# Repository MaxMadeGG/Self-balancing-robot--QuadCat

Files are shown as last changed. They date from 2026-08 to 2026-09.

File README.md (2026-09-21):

# Self-balancing robot- QuadCat

Wheel-legged balancing robot. Two gimbal motors drive the wheels with my own FOC code, two servos move the legs so it can crouch, and an MPU-6050 is used for balancing.
> **Status:** Work in progress. This repository currently contains the v2.0 custom PCB design, schematic and ownFOC code.
[DEMO](https://youtube.com/shorts/aNbwgdx8i7I?si=RKKSs-6FwYw2KxhV)
## Parts

| Part | Notes |
|---|---|
| ESP32 NodeMCU-32S | 30 pin |
| 2x SimpleFOC Mini (DRV8313) | needs at least 8 V |
| 2x gimbal motor | 7 pole pairs, ~35 Ω |
| 2x AS5600 | encoders, address 0x36 (can't be changed) |
| MPU-6050 | 0x68 |
| 2x MG90S | leg servos |
| 2x VL53L0X | distance sensors, not tested yet on the v2.0 |
| 2S LiPo 2600 mAh | |
| XL6009 boost | 10 V for the drivers |
| Buck converter | 5 V for the ESP32 and servos |
| 2x 220 µF cap | one on each driver, needed or the ESP32 resets |

## Schematic and PCB


The full schematic and PCB files are in the repo. The encoders both use address 0x36, so each one is on its own I2C bus.
It was made in easyEDA.
[gerber](self-balancing-robot-cat-gerber-v2.0.zip)
[schematic](schematic.epro2)
[PCB](PCB.epro2)

## Things to know

- GPIO 5, 12 and 27 need a 10k pulldown to GND. 5 and 12 are strapping pins, and if 12 is high at boot the ESP32 won't boot. Without the pulldown on the EN pins the drivers can turn on by themselves.
- AS5600: the chip has to face the magnet, about 1 mm away and flat. Check the AGC register, around 120-180 is good, 255 means too far.
- Reading the MPU at 2 kHz on the same bus as an encoder didn't work. 200 Hz is fine.
- Trim the header pins! Two pins touched on a driver (EN and nFAULT), the driver stayed on all the time and it killed an ESP32.

## Problems I had

Board v1:
- only one GND pin was really connected, it worked on USB but not on battery
- broken trace to SV2
- the two I2C buses were merged, so both encoders answered on 0x36 (couldn't fix)
- no caps on the drivers, the ESP32 reset during calibration
- encoder cables crossed and encoder direction inverted (fixed in code)
> **Note:** These v1 issues have all been resolved in the v2 layout included in this repository.

Board v2:
[gerber](self-balancing-robot-cat-gerber-v2.0.zip)
[schematic](schematic.epro2)
[PCB](PCB.epro2)
- motor 1 IN3 and EN were swapped in my code, so motor 1 only twitched. Took a while to find...
- SV2 is on GPIO12, not 13
- encoders were mounted the wrong way and too far from the magnet

## Software

I don't use the SimpleFOC library. On my board it didn't output any PWM, so I wrote my own [FOC](Quad-code-ownFOC.zip) using ledcWrite. The servos also use ledcWrite directly instead of ESP32Servo, so they don't fight with the motors over timers.

The control loop runs at a fixed 2 kHz. More about the code later.

## To do

- [ ] pulldowns on 5, 12 and 27
- [ ] test the lasers and battery reading
- [ ] finish the body
- [ ] balance loop
- [ ] ESP-NOW remote - connect to Kode dot and the Pinetime watch to control the robot by yourself
- [ ] make the robot autonomous

## Mechanical

Coming later...
You can still make your own robot with this working PCB, you will just need to tune the code (me i can't due to the ESP32 that broke)

## License

See [LICENSE](LICENSE.md).

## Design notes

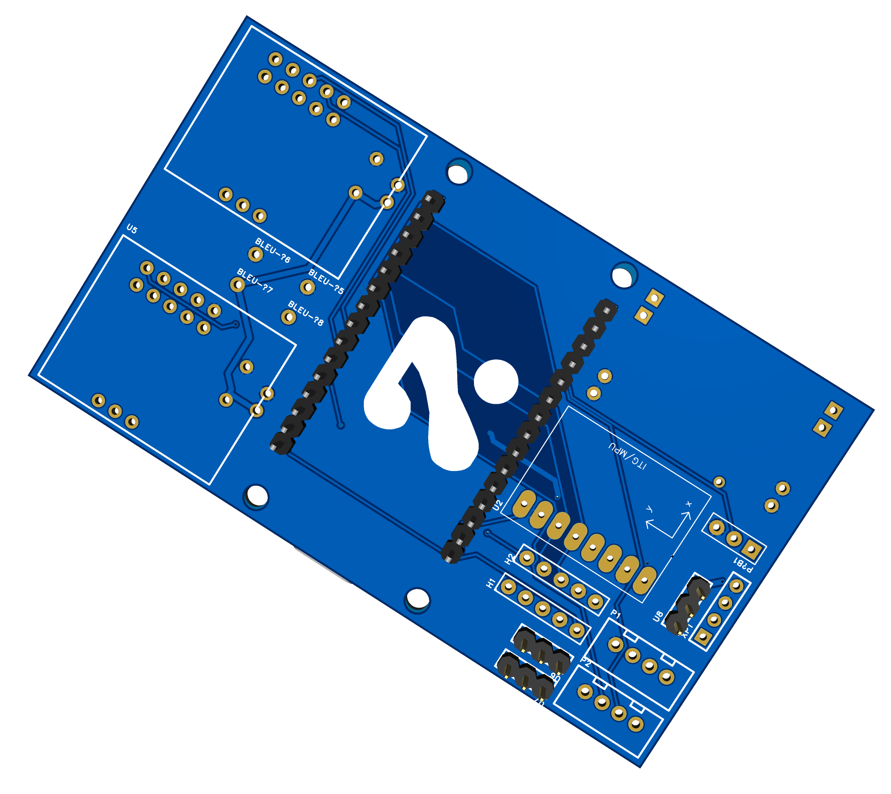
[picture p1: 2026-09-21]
3D_PCB.png

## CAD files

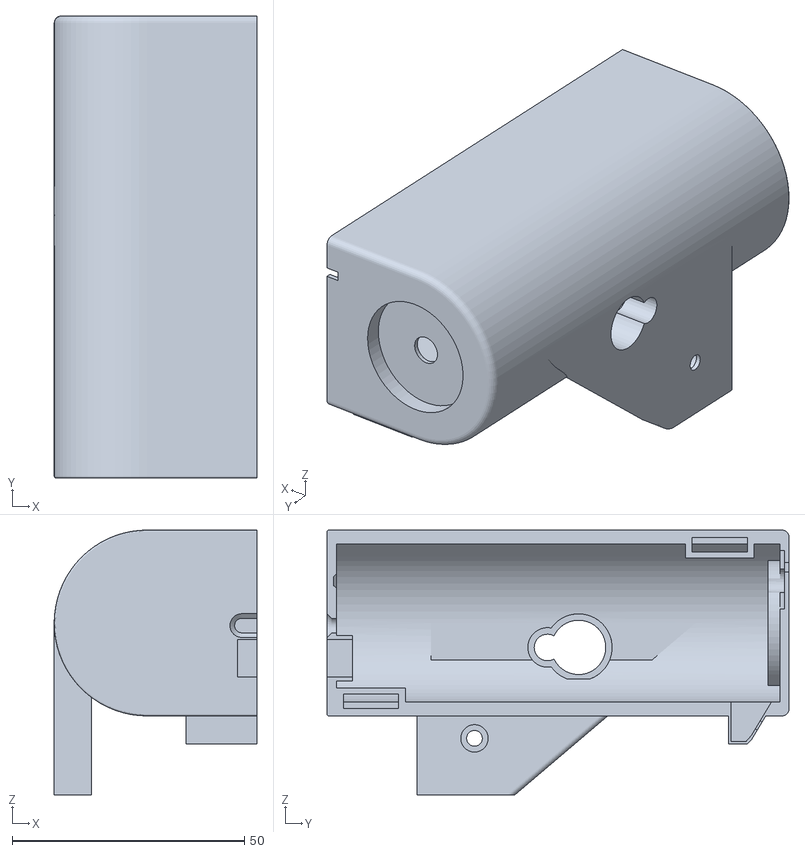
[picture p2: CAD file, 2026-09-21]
full-body-bot-on.stl
43.6 x 99.4 x 57.0

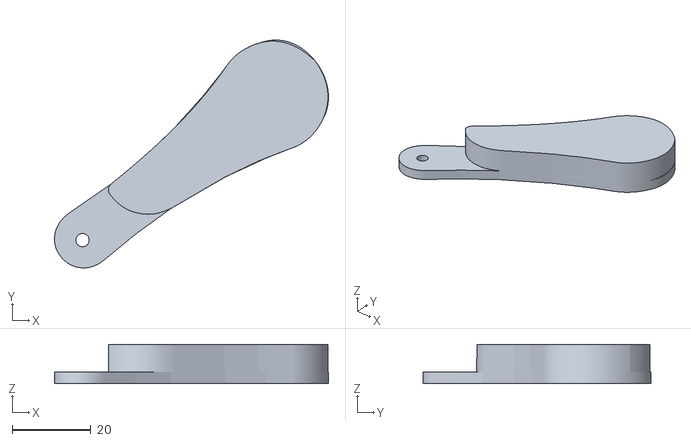
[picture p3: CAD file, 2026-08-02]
right-leg-main.stl
69.8 x 58.0 x 10.0

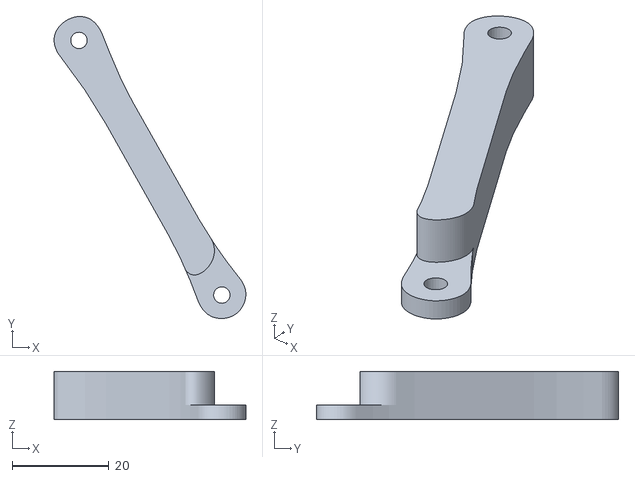
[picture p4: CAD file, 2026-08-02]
leg-main-hold.stl
39.6 x 62.4 x 10.0

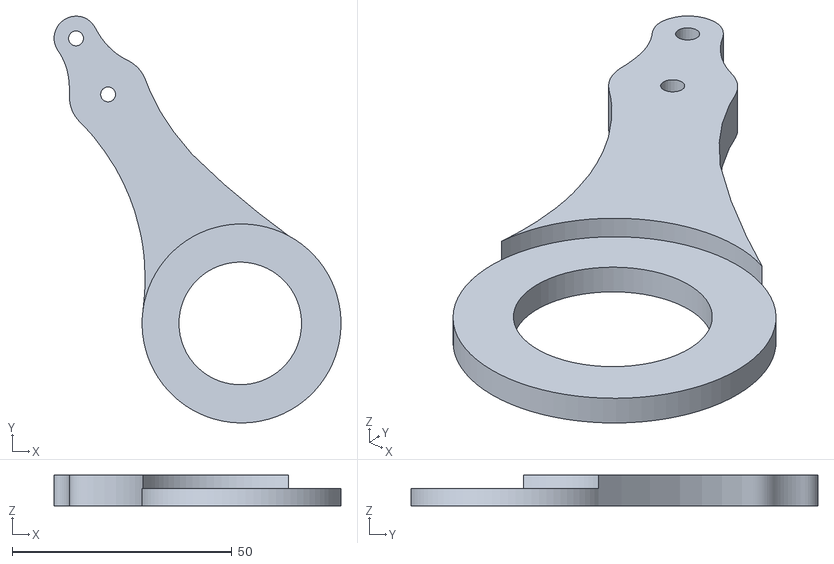
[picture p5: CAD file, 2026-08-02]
main-leg-right.stl
65.3 x 92.6 x 7.00

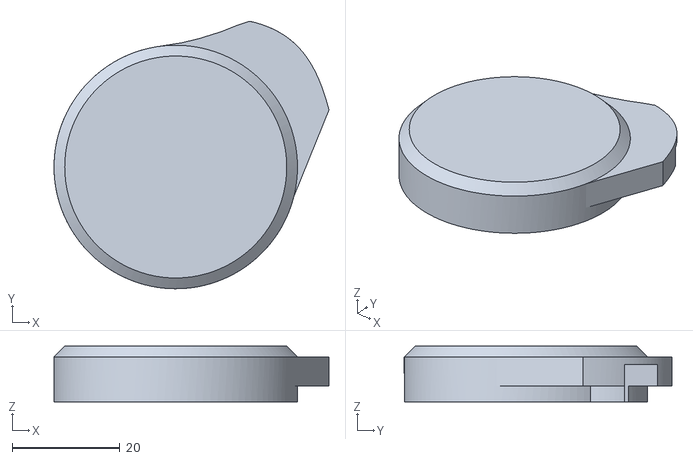
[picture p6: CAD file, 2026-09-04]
motor-leg-cover.stl
51.1 x 49.7 x 10.4

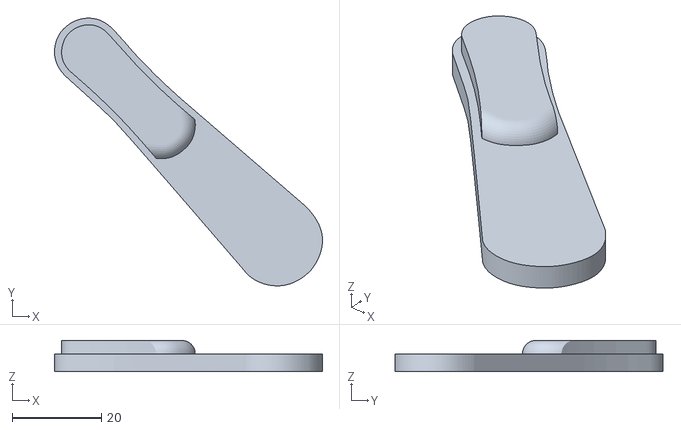
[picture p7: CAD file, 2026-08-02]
right-leg-holdr.stl
60.2 x 60.1 x 7.00

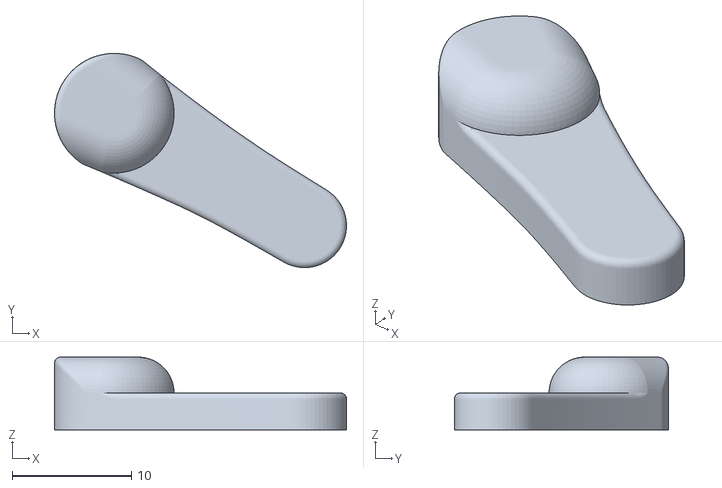
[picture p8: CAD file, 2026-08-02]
right-leg-prot_h.stl
24.4 x 17.9 x 6.10

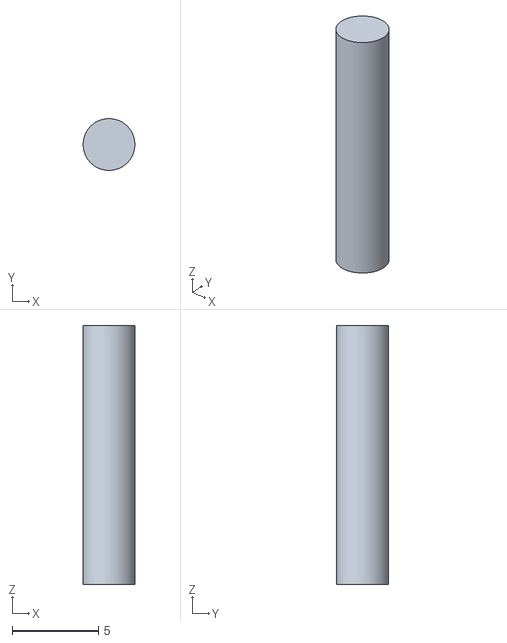
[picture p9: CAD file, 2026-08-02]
mount-bar-ptg.stl
3.00 x 3.00 x 15.0

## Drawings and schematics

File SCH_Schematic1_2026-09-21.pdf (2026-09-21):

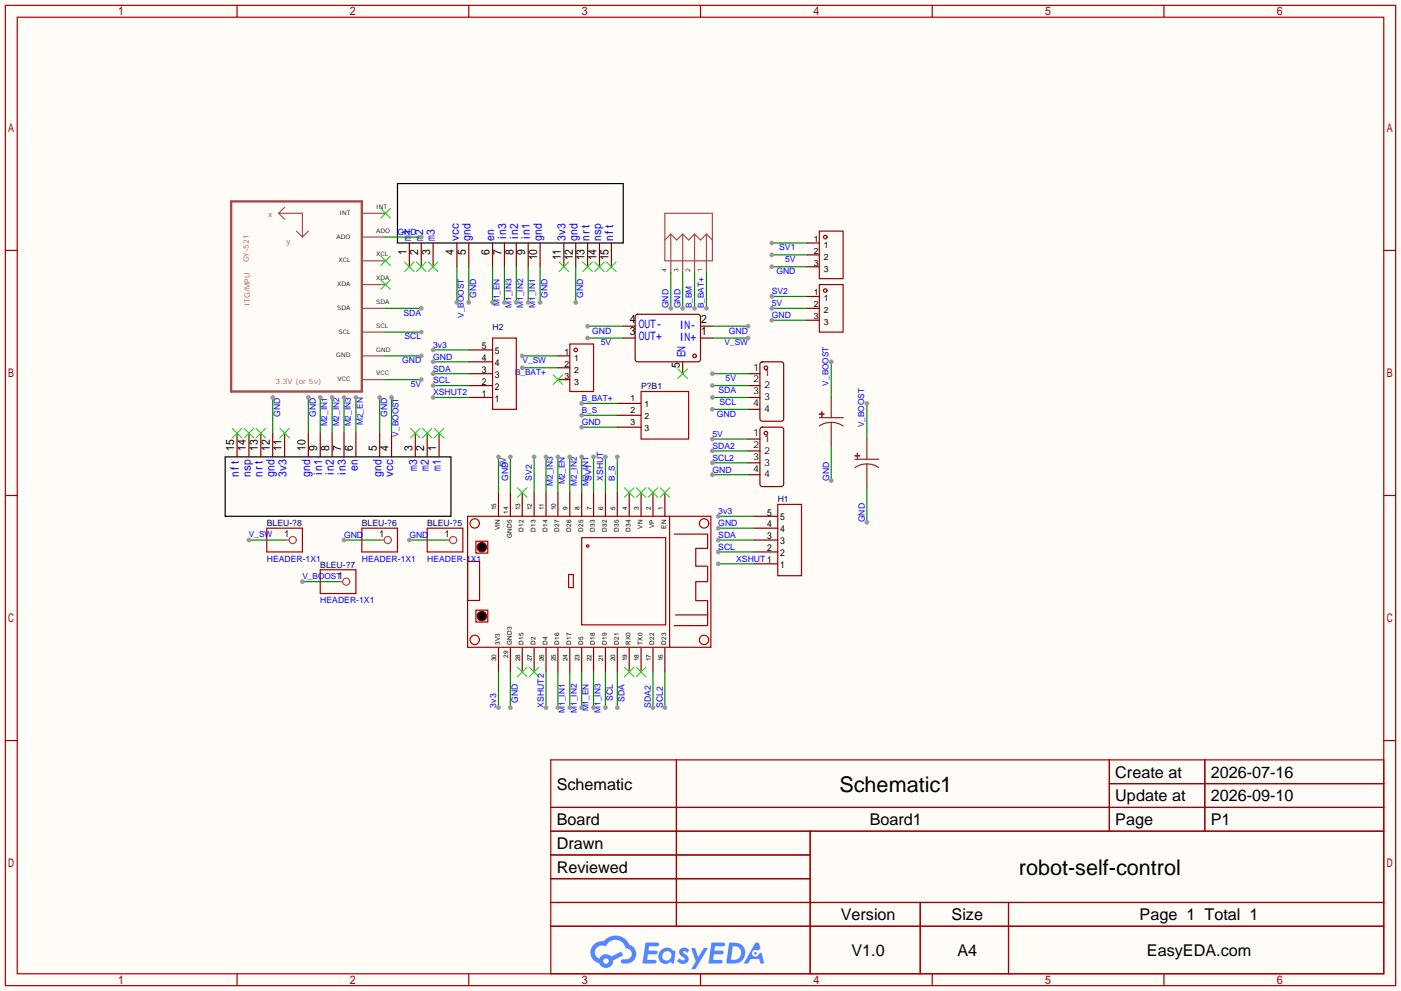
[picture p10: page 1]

Schematic | Schematic1 | Create at | 2026-07-16

Update at | 2026-09-10

Board | Board1 | Page | P1
Drawn | | robot-self-control
Reviewed

Version | Size | Page 1 Total 1
V1.0 | A4 | EasyEDA.com

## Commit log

2026-08-26 Update self-balancing robot control logic
    Refactor PID control variables and improve gyro calibration.
2026-08-28 Create BOM with shopping list and part links
    Added a shopping list with components and links to parts.
2026-08-28 Revise parts list reference in README
    Updated the README to reference the BOM file for parts list instead of listing them directly.
2026-09-21 Revise README for QuadCat project
    Updated project name and details, added schematic and PCB section, and revised troubleshooting notes.
2026-09-21 Update README with VL53L0X testing information
    Clarify testing status of VL53L0X distance sensors in v2.0.
2026-09-21 Update README with schematic tool and GPIO notes
    Added information about easyEDA and GPIO pulldown requirements.
2026-09-21 Revise BOM format and add part links
    Updated the shopping list format and added links to parts.
2026-09-21 Revise BOM format and add parts links
    Updated the shopping list format and added links to parts and filament types.
2026-09-21 Update README with PCB image and I2C details
    Added schematic image and clarified encoder I2C bus usage.
